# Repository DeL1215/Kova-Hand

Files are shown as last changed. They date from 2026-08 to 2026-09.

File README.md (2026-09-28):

# Kova Hand

[繁體中文](README.md) | [English](README.en.md)

Kova Hand 是一款開源、由腱繩驅動的低成本機械手，核心材料成本控制在新台幣 1,000 元以內。專案包含 3D 列印模型、ESP32-C3 韌體與 Windows 桌面控制軟體，可透過 BLE 獨立控制五根手指，並選用攝影機手勢跟隨或 LLM 自然語言動作控制。

## 成品展示

<p align="center">
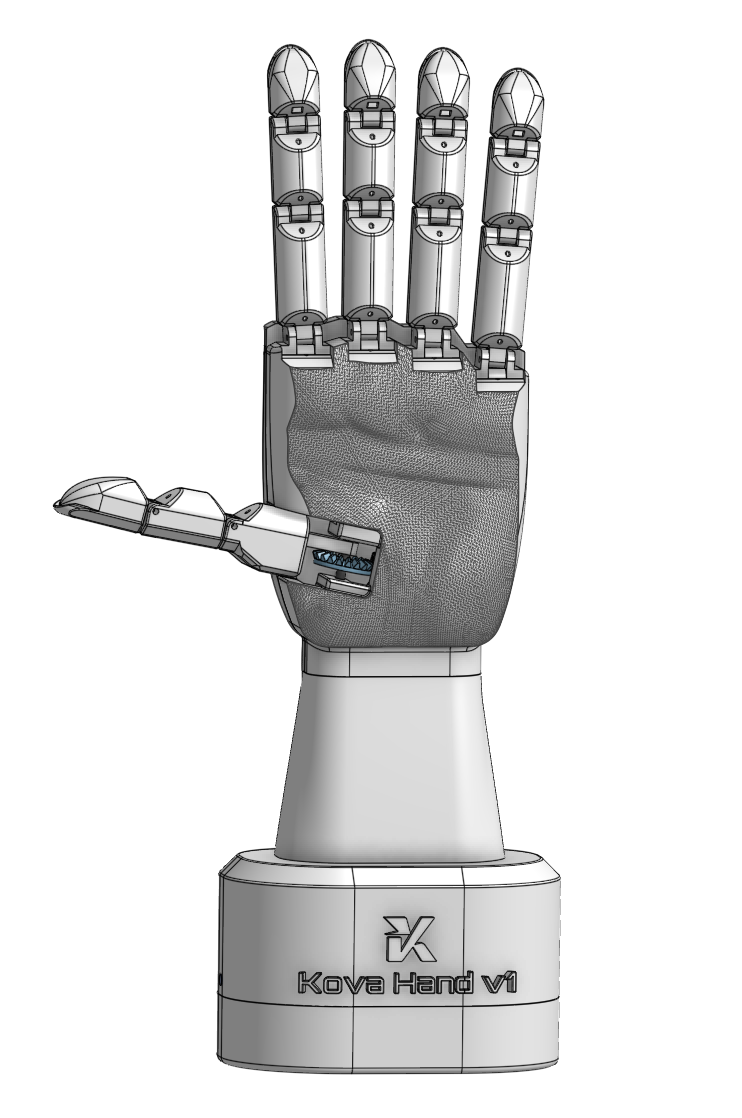
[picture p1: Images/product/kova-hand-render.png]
Kova Hand 機械手模型
  
</p>

### 桌面控制軟體

<p align="center">
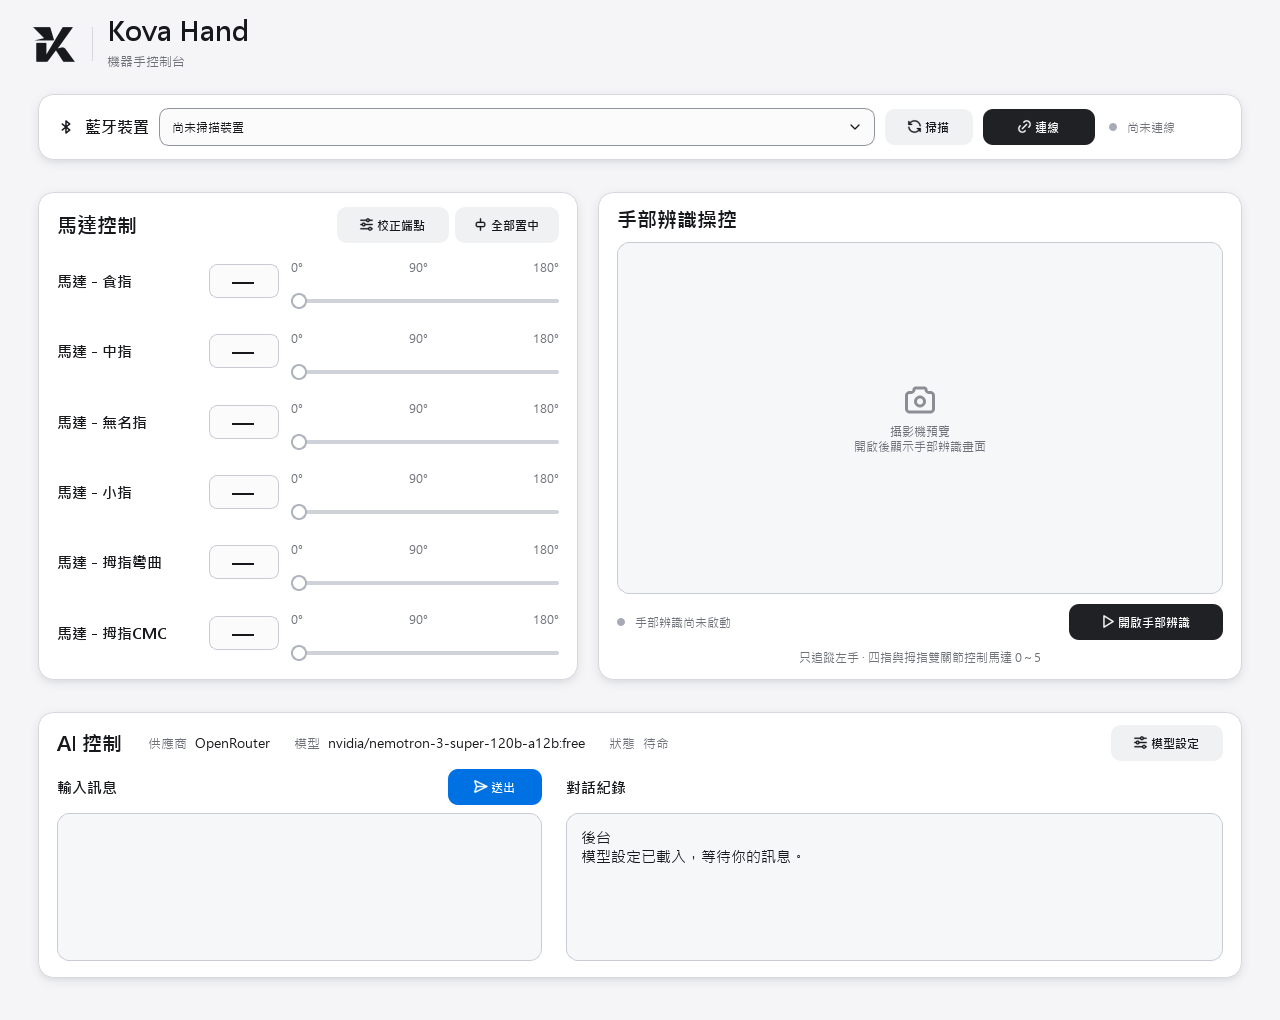
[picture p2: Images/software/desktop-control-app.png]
Kova Hand 桌面控制軟體介面
  
</p>

## 主要功能

- 獨立調整與控制五根手指
- 透過 BLE 無線連接 ESP32-C3 SuperMini
- 使用 MediaPipe 即時辨識並跟隨手部動作
- 透過 LLM 理解自然語言指令並執行對應動作
- 支援伺服馬達端點校正
- 提供圖形化桌面控制軟體

## 硬體需求與材料清單

以下價格為新台幣參考價格，未含運費。

| 材料 | 數量 | 參考價格 | 用途 |
|---|---:|---:|---|
| ESP32-C3 SuperMini 開發板 | 1 | NT$80 | BLE 通訊與主要控制 |
| 已焊接 PCA9685 伺服馬達驅動板 | 1 | NT$98 | 控制六顆伺服馬達 |
| SY8205 5V／5A 降壓模組 | 1 | NT$50 | 將外部電源降壓至 5V，供伺服馬達使用 |
| 5.5 × 2.1 mm DC 母座轉螺絲端子 | 1 | NT$5 | 連接外部電源 |
| MG90S 180° 伺服馬達 | 6 | NT$348 | 控制五根手指，其中拇指使用兩顆 |
| 0.8 mm 以下透明尼龍釣魚線 | 適量 | NT$50 | 作為驅動手指的腱繩 |
| 18～20 AWG 紅黑電源線 | 約 20 cm | NT$5 | 連接 DC 母座、SY8205 與 PCA9685 |
| 2.54 mm 母對母杜邦線 | 4 | NT$10 | 連接 ESP32-C3 SuperMini 與 PCA9685 |
| PLA 或 PETG 3D 列印耗材 | 依據實際用量 | NT$150 | 列印機械手本體與底座 |
| M2 × 6 mm 自攻螺絲 | 20 | NT$20 | 固定機械結構 |
| M2 × 12 mm 自攻螺絲 | 20 | NT$20 | 固定機械結構 |
| Ø2 × 10 mm 定位銷 | 5 | NT$10 | 手指關節定位 |
| Ø2 × 16 mm 定位銷 | 10 | NT$20 | 手指關節定位 |
| Ø3 × 26 mm 定位銷 | 1 | NT$5 | 機械結構定位 |
| 線徑 0.4 × 外徑 4 × 長 70／80 mm 拉伸彈簧 | 5 | NT$20 | 手指回彈 |
| 線徑 0.4 × 外徑 4 × 長 60 mm 拉伸彈簧 | 1 | NT$4 | 拇指回彈 |

**預估核心材料成本：約 NT$895**

3D 列印成本僅估算耗材，不包含印表機、電費與代印費用。

DC 端子須使用 **5.5 mm 外徑、2.1 mm 內徑的母座轉螺絲端子**；SY8205 須選擇 **5V 輸出版本**。

### 材料外觀參考

下圖僅供辨識外觀，請以材料表中的規格與數量為準。

| | | |
|:---:|:---:|:---:|
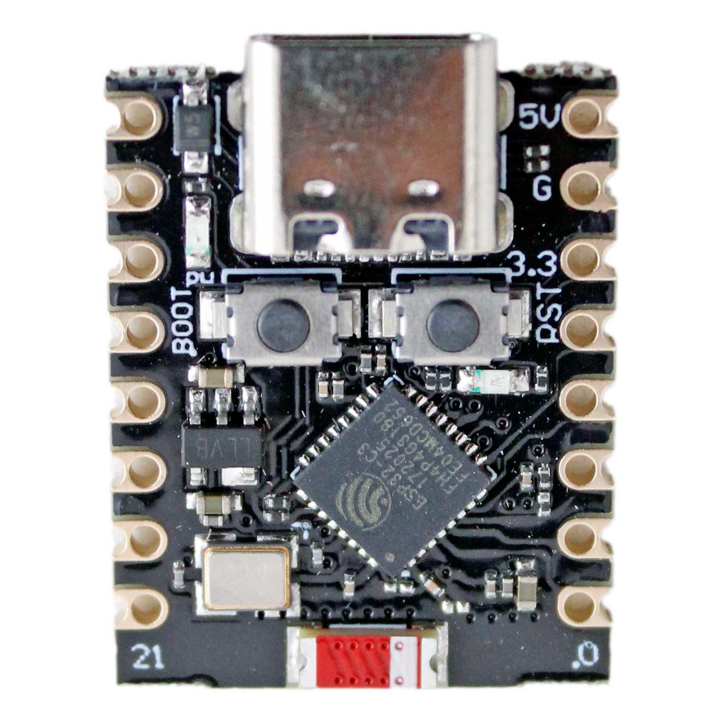
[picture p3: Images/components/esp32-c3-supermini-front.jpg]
ESP32-C3 SuperMini 開發板
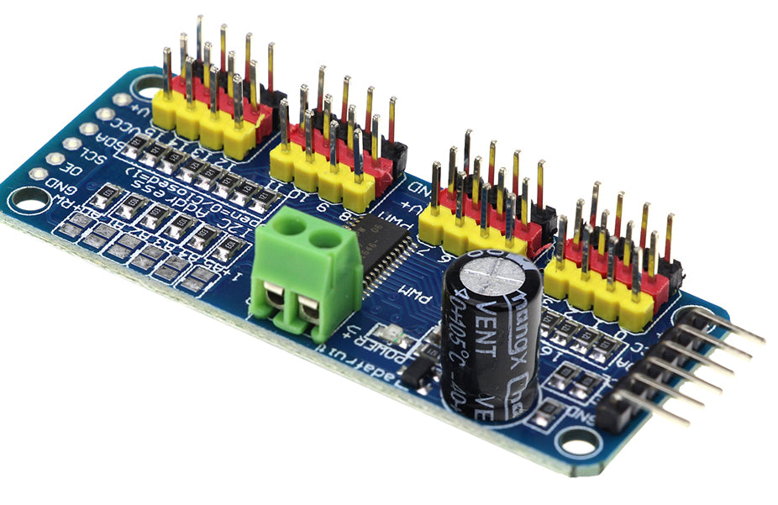
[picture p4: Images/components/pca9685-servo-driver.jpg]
已焊接 PCA9685 伺服馬達驅動板
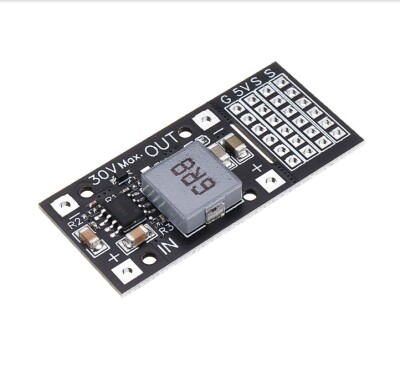
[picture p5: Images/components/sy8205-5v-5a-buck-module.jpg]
SY8205 5V 5A 降壓模組
| <br>ESP32-C3 SuperMini | <br>已焊接 PCA9685 驅動板 | <br>SY8205 5V／5A 降壓模組 |
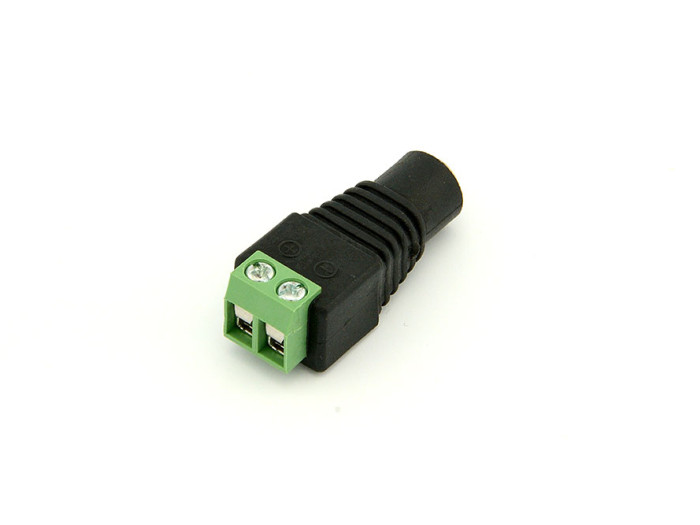
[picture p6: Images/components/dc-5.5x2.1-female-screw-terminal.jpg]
5.5 × 2.1 mm DC 母座轉螺絲端子
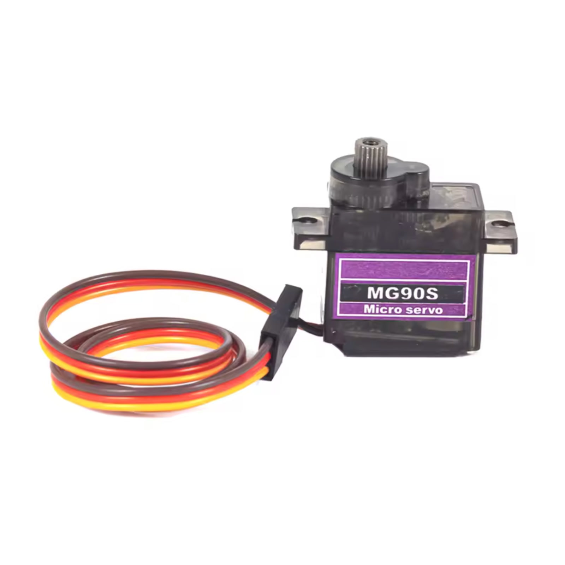
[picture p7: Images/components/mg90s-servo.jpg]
MG90S 180 度伺服馬達
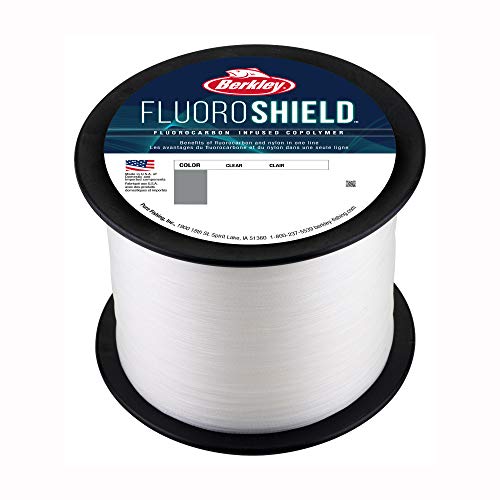
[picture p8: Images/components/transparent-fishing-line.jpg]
透明尼龍釣魚線
| <br>5.5 × 2.1 mm DC 母座 | <br>MG90S 伺服馬達 | <br>透明尼龍釣魚線 |
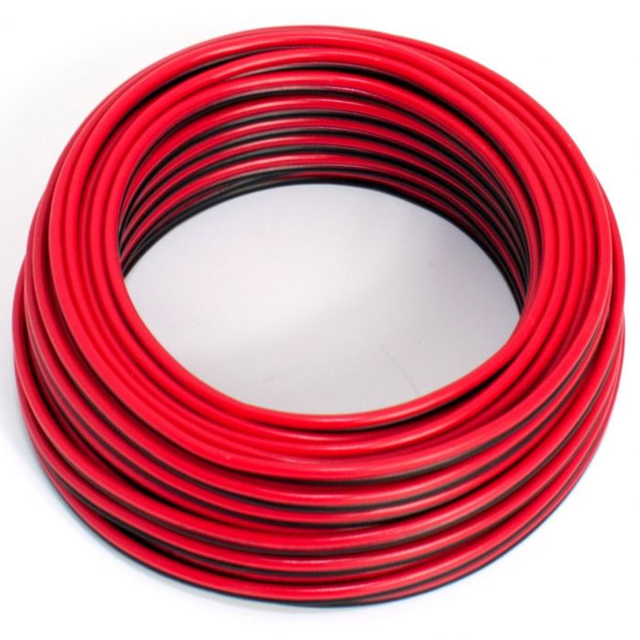
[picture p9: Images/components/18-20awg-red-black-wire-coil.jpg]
18 至 20 AWG 紅黑電源線線捲
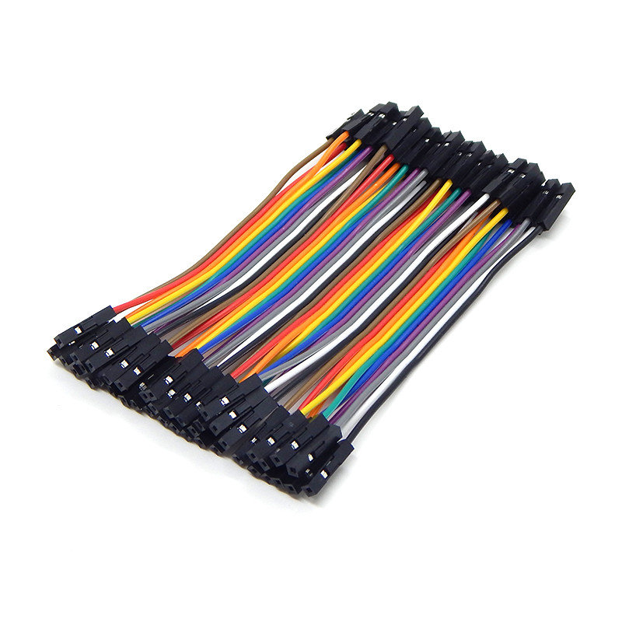
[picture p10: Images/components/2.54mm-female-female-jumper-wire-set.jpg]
多色 2.54 mm 母對母杜邦線組
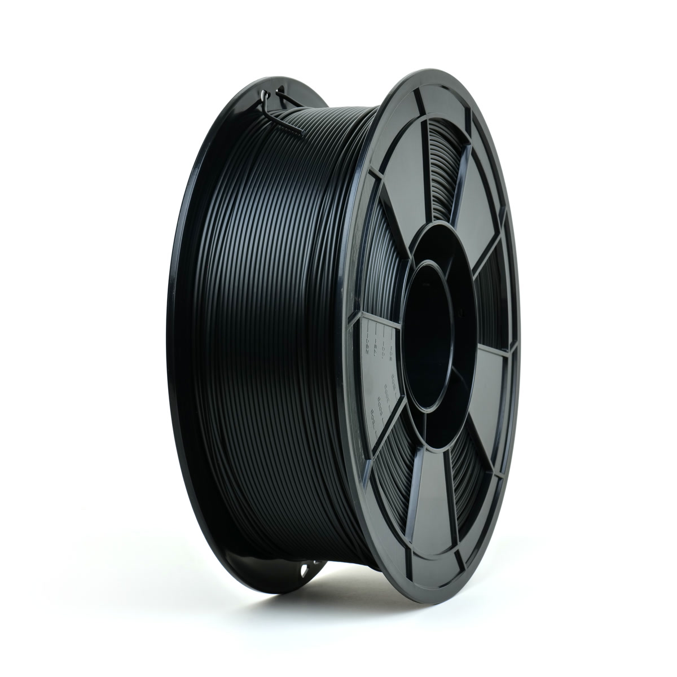
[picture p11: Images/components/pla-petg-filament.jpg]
PLA 或 PETG 列印耗材
| <br>18～20 AWG 紅黑電源線 | <br>2.54 mm 母對母杜邦線 | <br>PLA／PETG 列印耗材 |
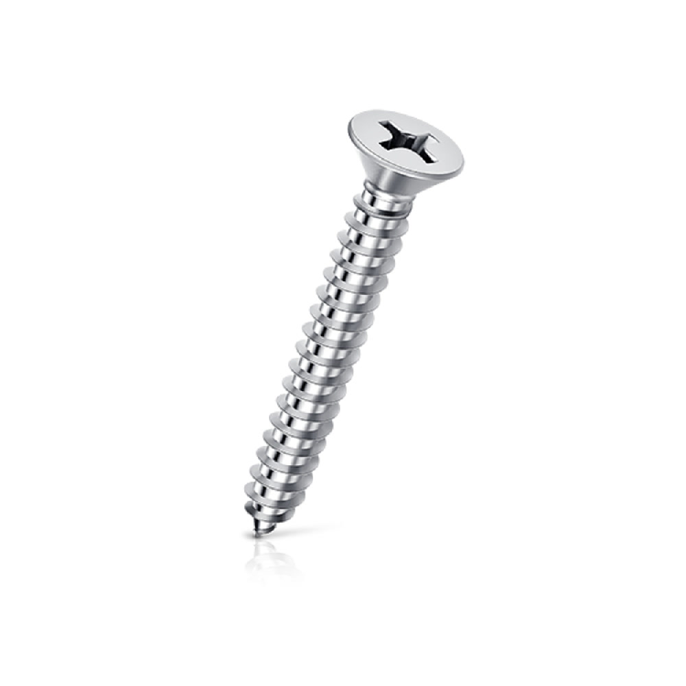
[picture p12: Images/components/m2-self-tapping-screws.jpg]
M2 自攻螺絲
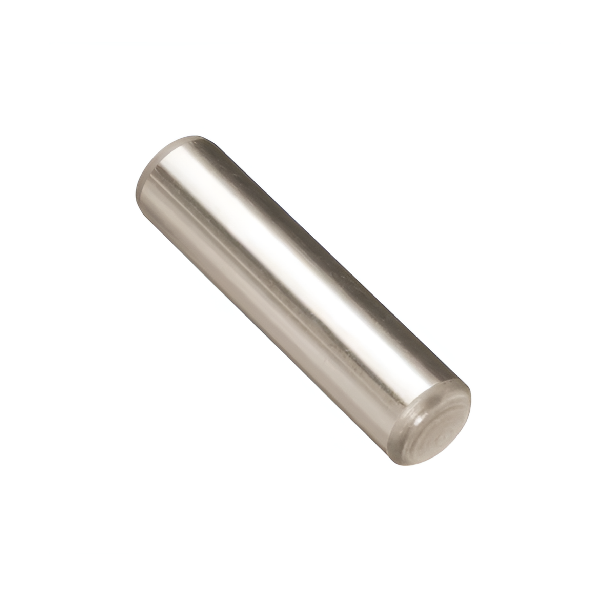
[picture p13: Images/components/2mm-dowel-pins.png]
2 mm 定位銷
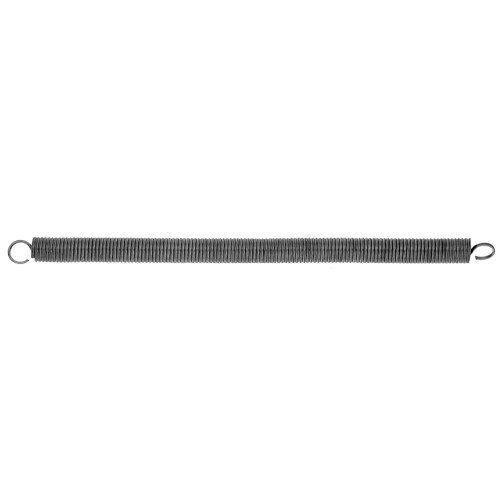
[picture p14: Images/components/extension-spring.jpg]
拉伸彈簧
| <br>M2 自攻螺絲 | <br>2 mm 定位銷 | <br>拉伸彈簧 |

### 額外設備

- USB Type-C 傳輸線，用於 ESP32-C3 SuperMini 燒錄與除錯
- DC 電源線與電源供應器
- 攝影機，僅手部動作跟隨功能需要

## 3D 列印模型

<p align="center">
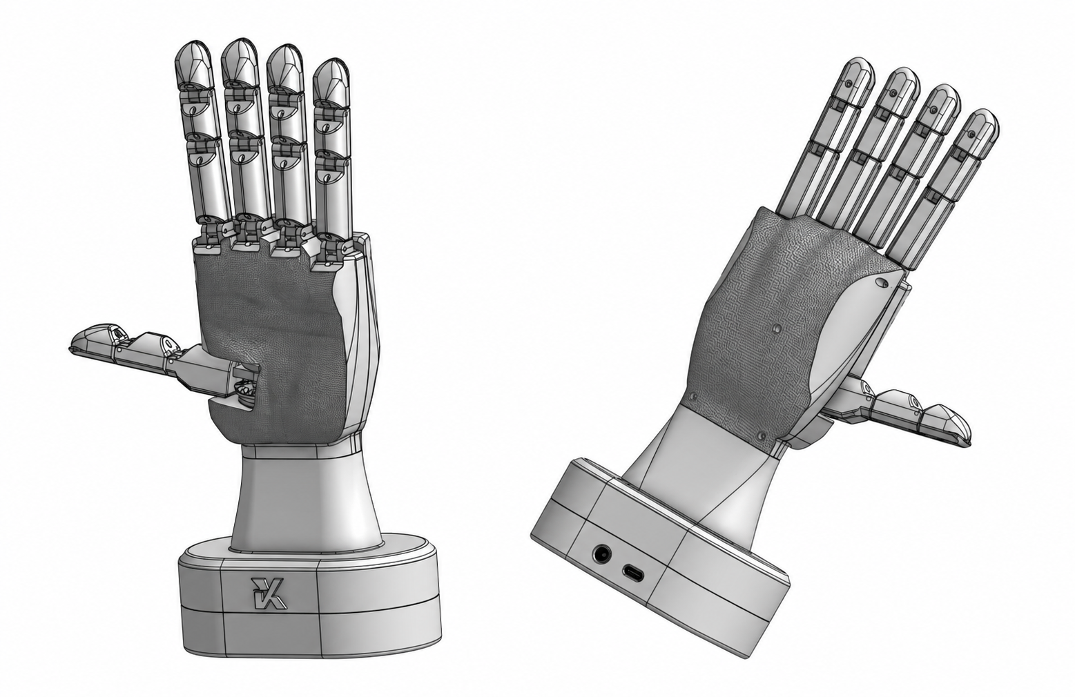
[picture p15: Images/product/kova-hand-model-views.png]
Kova Hand 3D 模型雙視角
  
</p>

可在 [Onshape 線上模型](https://cad.onshape.com/documents/ccffffec5822f67dead6a1cb/w/ebebf107b7355267c1a8c3b4/e/881fbe2581adab1d2883eabd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) 檢視模型與組裝結構。

### STL 模型

STL 模型將透過 [GitHub Releases](https://github.com/DeL1215/Kova-Hand/releases) 提供。

### Bambu Studio 3MF 配置

另提供 Bambu Studio 3MF 列印配置。

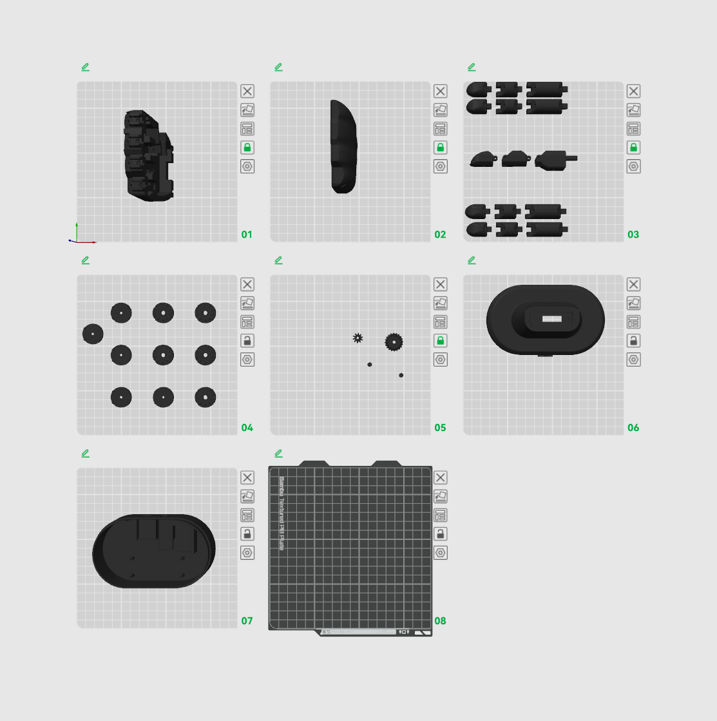
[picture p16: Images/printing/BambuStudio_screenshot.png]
Kova Hand 零件在 Bambu Studio 中的列印配置


> [!WARNING]
> **齒輪不建議使用啞光 PLA 或其他啞光耗材。** 啞光材料通常較脆，齒牙受力時容易崩斷；建議改用一般 PLA、PLA+ 或韌性較好的 PETG。

## 電路接線

Kova Hand 電路接線圖

| 來源 | 連接至 |
|---|---|
| DC 母座 `+` | SY8205 `IN+` |
| DC 母座 `−` | SY8205 `IN−` |
| SY8205 `OUT+` | PCA9685 `V+` |
| SY8205 `OUT−` | PCA9685 電源端子 `GND` |
| ESP32-C3 `3.3V` | PCA9685 `VCC` |
| ESP32-C3 `GPIO8` | PCA9685 `SDA` |
| ESP32-C3 `GPIO9` | PCA9685 `SCL` |
| ESP32-C3 `GND` | PCA9685 `GND` |

PCA9685 的 CH0～CH5 依序連接食指、中指、無名指、小指、拇指彎曲與拇指 CMC 伺服馬達。

## 韌體燒錄

韌體支援 PlatformIO 與 Arduino IDE。

### PlatformIO

1. 安裝 Visual Studio Code 與 PlatformIO IDE 擴充套件。
2. 使用 PlatformIO 開啟專案中的 `firmware` 資料夾。
3. 使用具備資料傳輸功能的 USB Type-C 線連接 ESP32-C3 SuperMini。
4. 選擇環境 `esp32-c3-devkitm-1`，點擊 **Upload**。

### Arduino IDE

1. 安裝 **ESP32 by Espressif Systems 2.0.17**。
2. 在函式庫管理員安裝：
   - `Adafruit PWM Servo Driver Library 3.0.3`
   - `NimBLE-Arduino 1.4.3`
3. 開啟 `firmware/KovaHand/KovaHand.ino`。
4. 選擇 **ESP32C3 Dev Module** 與正確的連接埠，將 **USB CDC On Boot** 設為 **Enabled**。
5. 點擊 **上傳**。

## 軟體安裝

### 系統需求

- Windows 10 或 11，並具備 Bluetooth Low Energy
- Python 3.11
- Git
- 網路連線，用於安裝套件與下載 MediaPipe 模型

攝影機與 LLM API Key 為選用項目。

### 1. 下載專案

```powershell
git clone https://github.com/DeL1215/Kova-Hand.git
cd Kova-Hand
```

### 2. 建立虛擬環境

```powershell
py -3.11 -m venv kova-hand-env
.\kova-hand-env\Scripts\Activate.ps1
```

### 3. 安裝必要套件

```powershell
python -m pip install -r requirements.txt
```

### 4. 下載手部辨識模型

```powershell
python scripts\download_hand_model.py
```

### 5. 確認安裝結果

```powershell
python scripts\check_install.py
```

## 啟動控制軟體

在專案根目錄執行：

```powershell
.\kova-hand-env\Scripts\Activate.ps1
python desktop-app\main.py
```

## 專案結構

```text
Kova-Hand/
├── Images/
│   ├── components/              # 電子零件參考圖
│   ├── printing/                # 列印配置畫面
│   ├── product/                 # 成品與模型展示圖
│   ├── software/                # 軟體介面畫面
│   └── wiring/                  # 電路接線圖
├── desktop-app/                 # 桌面控制軟體
│   ├── main.py                  # BLE 與手部辨識
│   ├── qt_ui.py                 # 圖形介面
│   ├── ai_chat.py               # LLM 控制
│   ├── config.py                # 控制參數
│   └── tests/                   # 軟體測試
├── firmware/
│   ├── KovaHand/KovaHand.ino    # Arduino IDE 韌體
│   ├── src/main.cpp             # PlatformIO 入口
│   └── platformio.ini           # PlatformIO 設定
├── scripts/
│   ├── download_hand_model.py   # 下載手部辨識模型
│   └── check_install.py         # 檢查安裝環境
├── .env.example                 # LLM 設定範例
├── requirements.txt             # Python 依賴
├── LICENSE-CODE                 # 程式碼授權
├── LICENSE-HARDWARE             # 模型與硬體授權
├── NOTICE                       # 第三方授權與告知事項
├── TRADEMARKS.md                # 名稱與 Logo 使用規範
├── README.md                    # 繁體中文說明
└── README.en.md                 # English documentation（規劃中）
```

## 開發狀態

核心硬體與控制功能已完成，目前以 Demo 版本發布。

## 授權

- 程式碼採用 [MIT License](LICENSE-CODE)。
- 3D 模型、硬體設計與專案文件採用 [CC BY-NC-SA 4.0](LICENSE-HARDWARE)。
- Kova Hand 名稱與 Logo 不包含在上述授權中，詳見 [TRADEMARKS.md](TRADEMARKS.md)。
- 商業使用 3D 模型或硬體設計前，請透過 GitHub 專案擁有者公開的聯絡方式洽談商業授權。

Copyright © 2026 Kova Hand Project

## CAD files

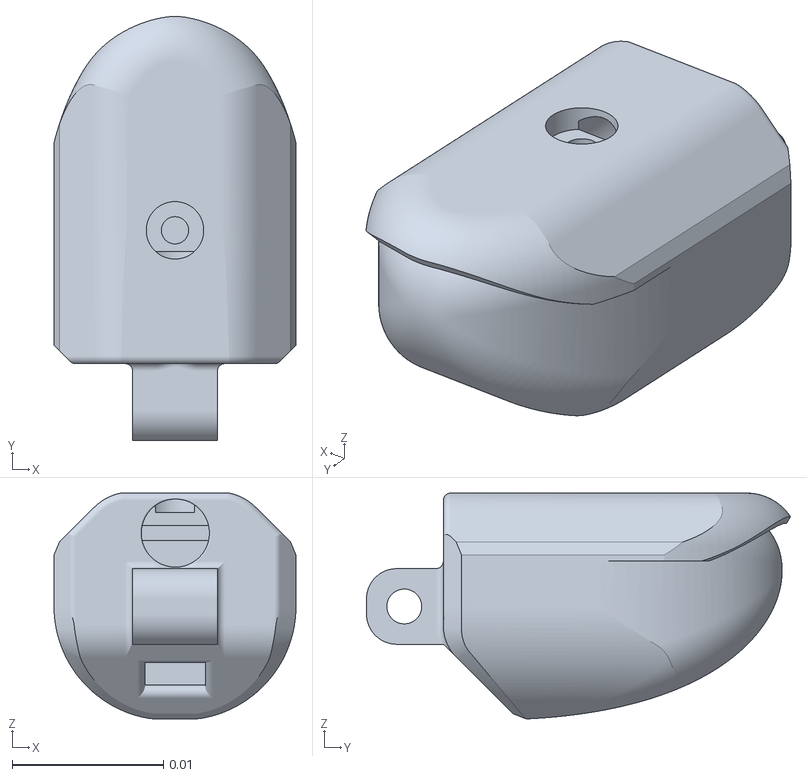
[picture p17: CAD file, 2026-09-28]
Models/DIP.stl
0.016 x 0.028 x 0.0149

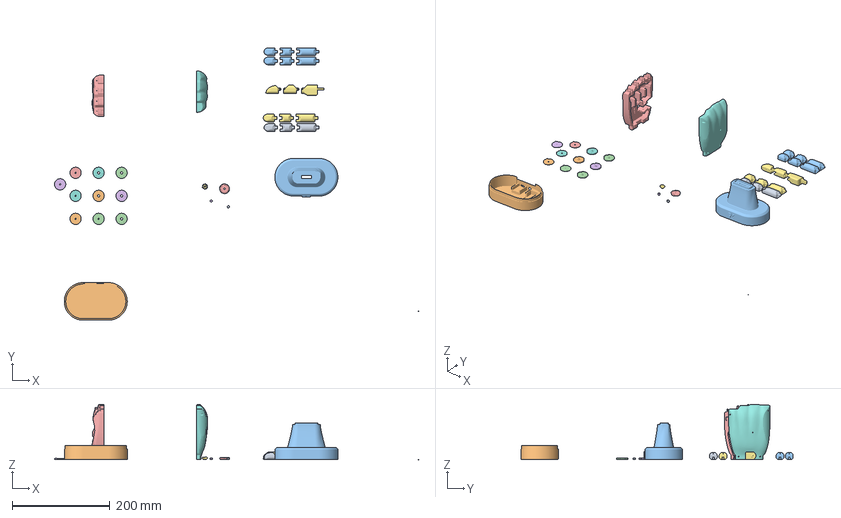
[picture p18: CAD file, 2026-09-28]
Printing.3mf
745.0 x 557.5 x 113.0 mm
收線舵盤.stl
Base1.stl
Base2.stl
Servo_Tendon_Spool_Part1.stl x 5
Gear_big
Gear_small
Part Studio 1 - Part 9.stl x 2
Finger x 4
Servo_Tendon_Spool_Part2.stl x 5
Hand_Front.stl
Thumb
Hand_Back.stl

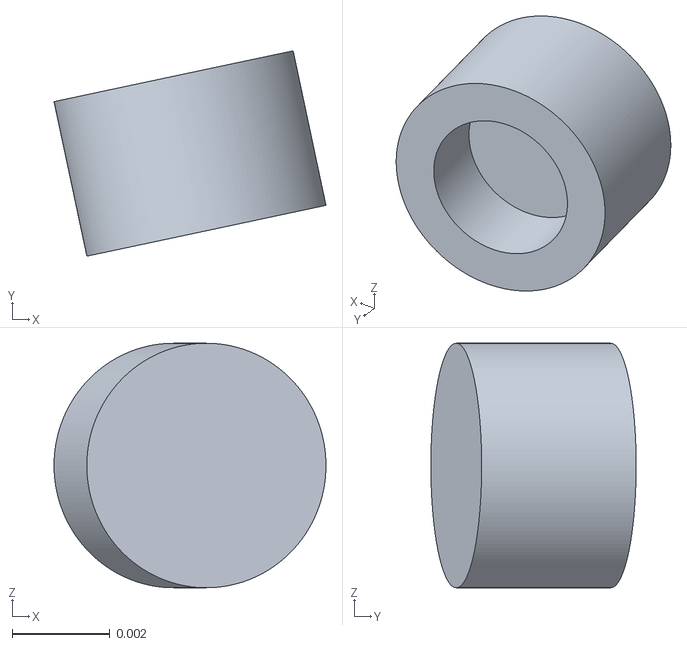
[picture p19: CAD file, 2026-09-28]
Models/Part 9.stl
0.00556 x 0.0042 x 0.005

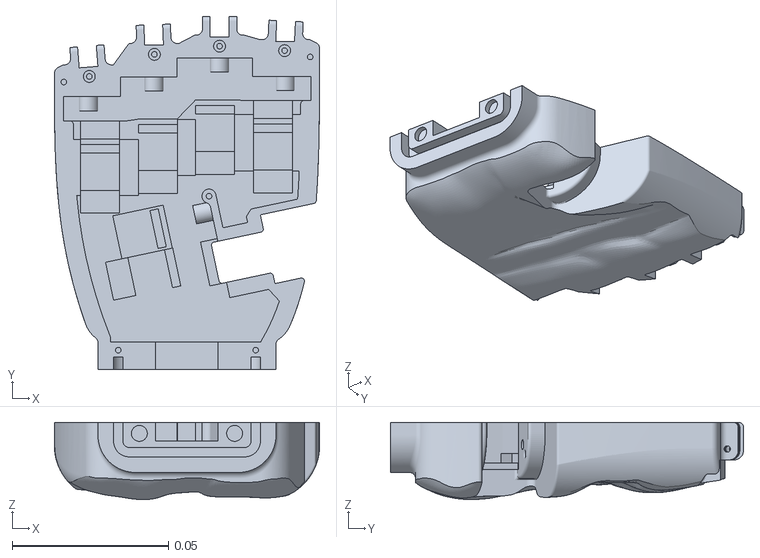
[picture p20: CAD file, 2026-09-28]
Models/Hand_Front.stl
0.0849 x 0.113 x 0.0247

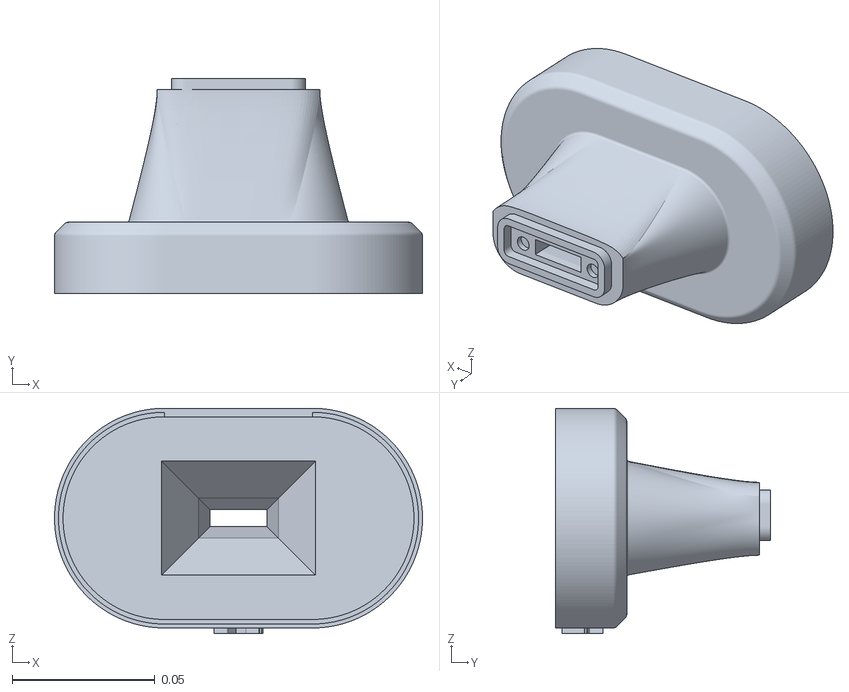
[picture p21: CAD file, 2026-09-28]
Models/Base2.stl
0.129 x 0.0754 x 0.079

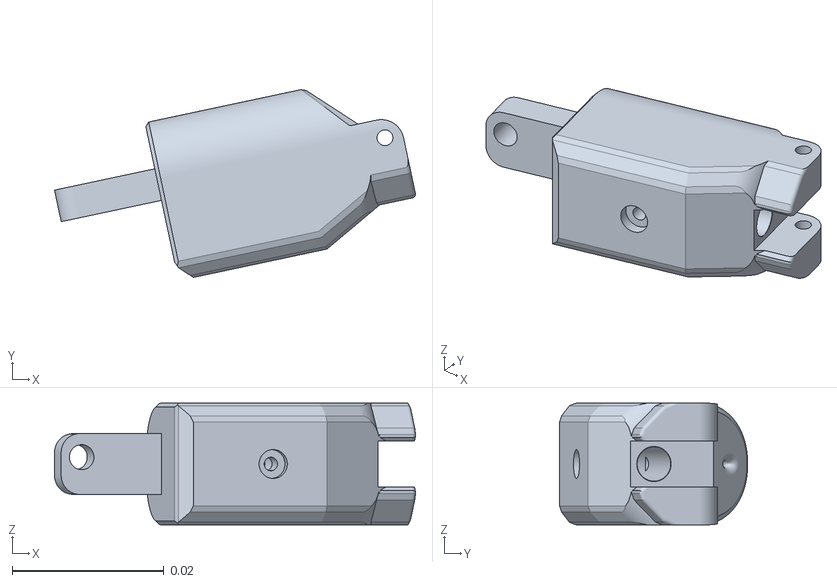
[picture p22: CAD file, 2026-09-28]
Models/thumb_CMC.stl
0.0475 x 0.0247 x 0.016

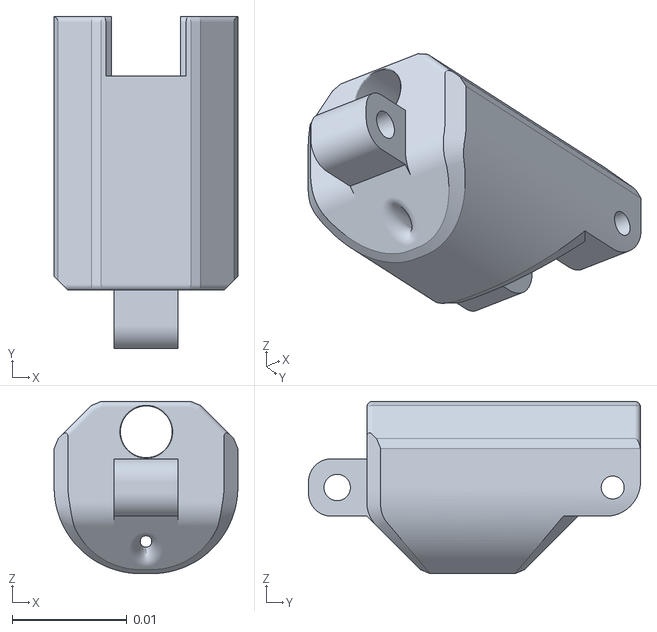
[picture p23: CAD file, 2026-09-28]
Models/PIP.stl
0.016 x 0.0289 x 0.015

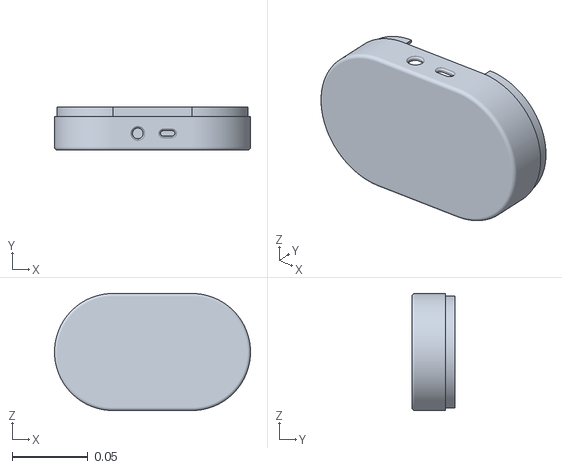
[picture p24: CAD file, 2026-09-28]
Models/Base1.stl
0.129 x 0.0285 x 0.077

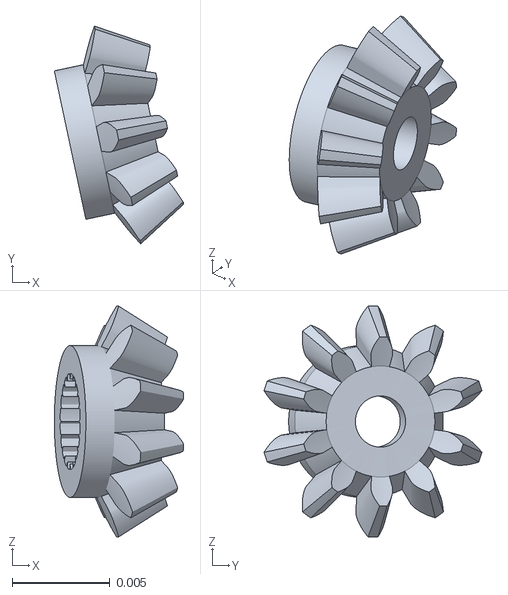
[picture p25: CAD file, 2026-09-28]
Models/Gear_small.stl
0.00662 x 0.0111 x 0.0118

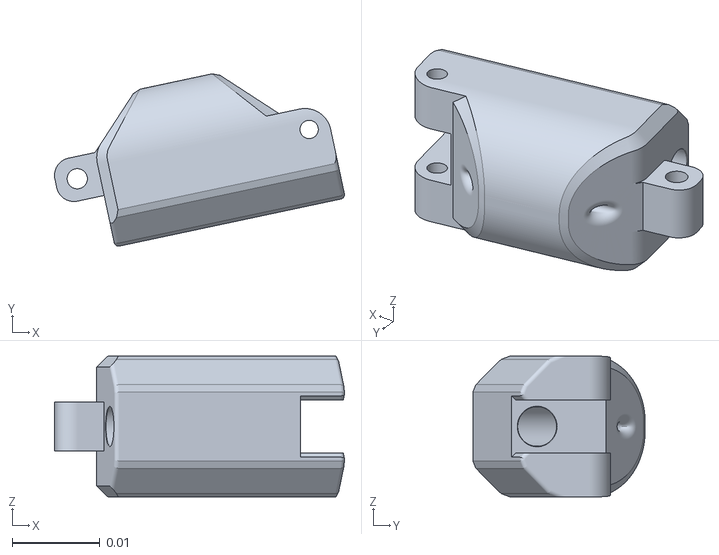
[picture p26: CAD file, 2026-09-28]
Models/thumb_PIP.stl
0.033 x 0.0196 x 0.016

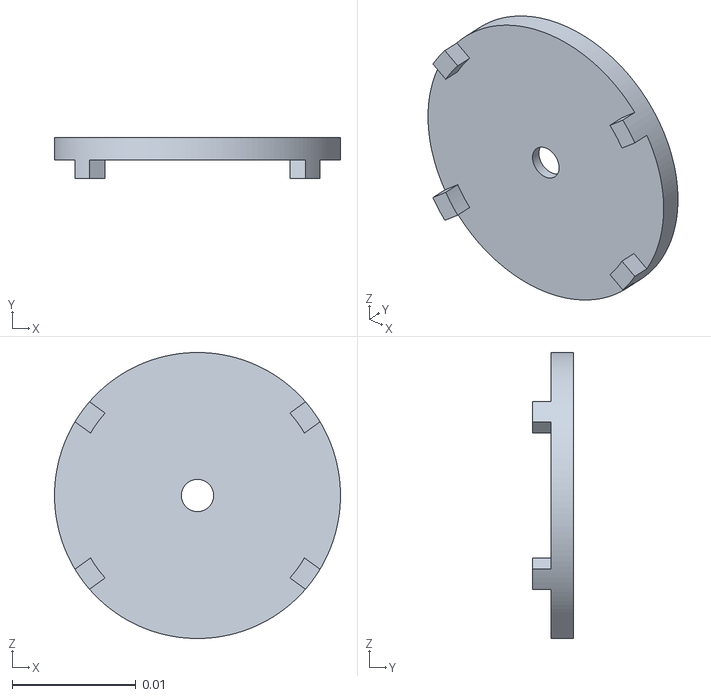
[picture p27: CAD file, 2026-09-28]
Models/Servo_Tendon_Spool_Part1.stl
0.0231 x 0.0033 x 0.0231

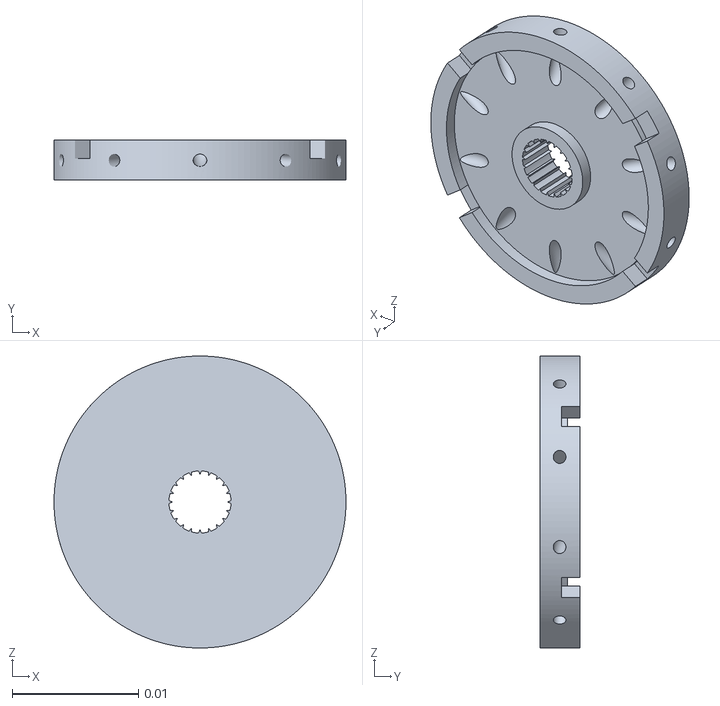
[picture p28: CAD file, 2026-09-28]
Models/Servo_Tendon_Spool_Part2.stl
0.0231 x 0.0032 x 0.0231

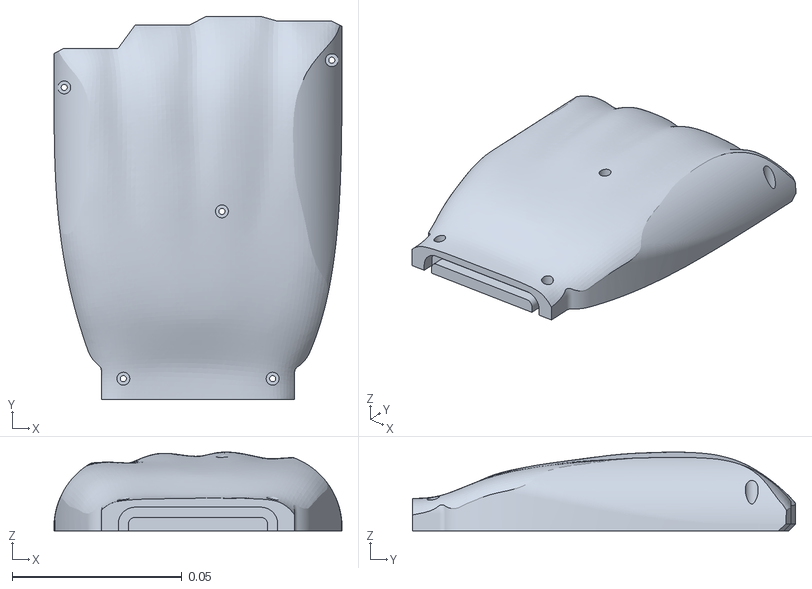
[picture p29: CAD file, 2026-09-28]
Models/Hand_Back.stl
0.0849 x 0.113 x 0.0232

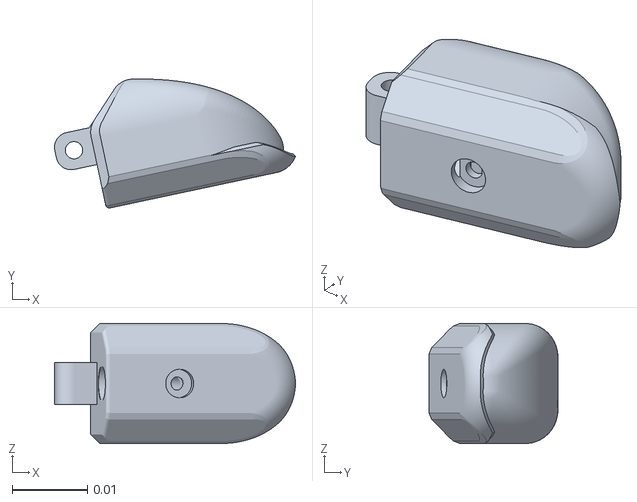
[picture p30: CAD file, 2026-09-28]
Models/thumb_DIP.stl
0.032 x 0.0171 x 0.016

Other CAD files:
列印.3mf
Models/MCP.stl
Models/Gear_big.stl

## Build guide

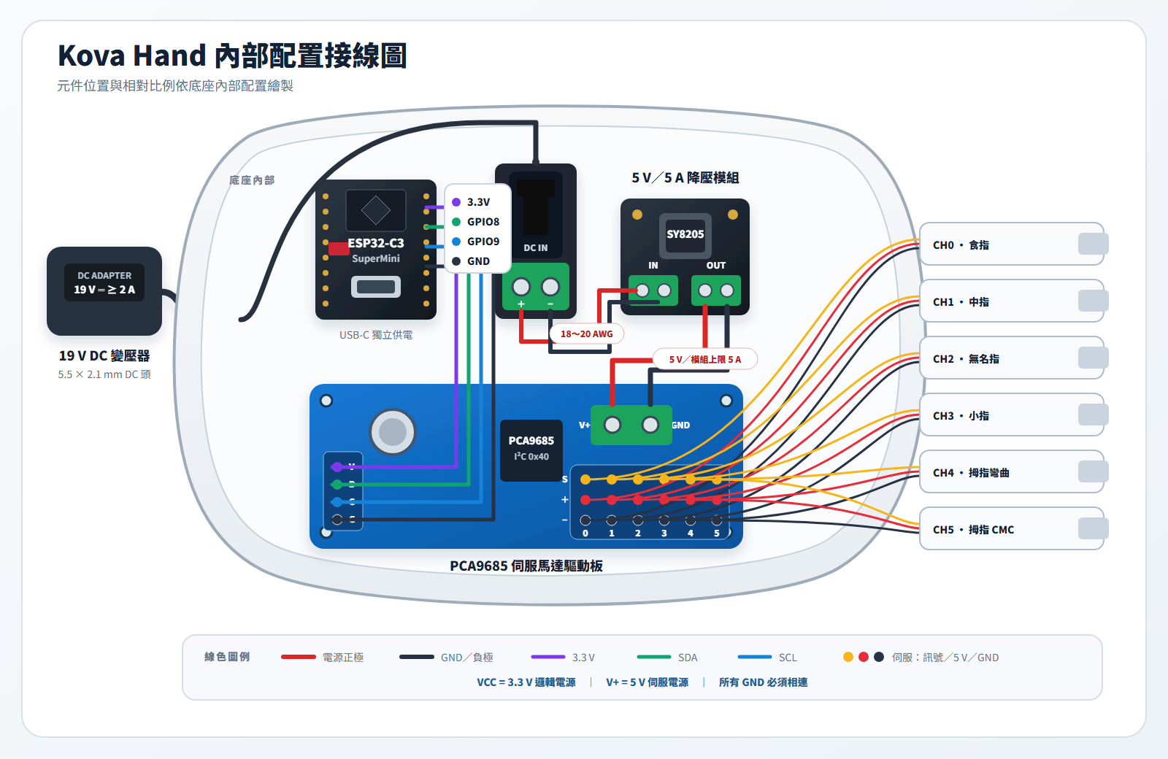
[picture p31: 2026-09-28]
Images/wiring/kova-hand-wiring.png

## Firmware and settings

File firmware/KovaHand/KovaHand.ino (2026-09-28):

// SPDX-FileCopyrightText: 2026 Kova Hand Project
// SPDX-License-Identifier: MIT

#include <Arduino.h>
#include <Wire.h>
#include <Adafruit_PWMServoDriver.h>
#include <NimBLEDevice.h>
#include <Preferences.h>

// ============================================================
// Kova Hand：ESP32-C3 + PCA9685 + BLE 六路舵機控制器
// 單路指令：S,通道,角度\n，例如 S,0,90
// 六馬達同步指令：7 bytes，'B' 後接 channel 0～5 的 uint8 角度。
// ============================================================

namespace Config {

// ESP32-C3 連接 PCA9685 的 I2C 腳位。
constexpr uint8_t SDA_PIN = 8;
constexpr uint8_t SCL_PIN = 9;

constexpr uint8_t PCA9685_ADDRESS = 0x40;
constexpr uint8_t SERVO_COUNT = 6;
constexpr uint16_t SERVO_FREQUENCY_HZ = 50;
constexpr uint16_t SERVO_UPDATE_INTERVAL_MS = 20;
// 20 ms 走 8 度：仍有漸進移動，但不會明顯落後於手勢。
constexpr uint8_t SERVO_MAX_STEP_DEG = 8;
constexpr uint8_t SERVO_START_ANGLE_DEG = 0;

// 每顆舵機獨立校正。舊馬達沿用原本可到 180° 的端點；
// 新批次 MG90S 使用較短脈寬，避免在終點撞限位後回抽。
struct ServoPulseRange {
  uint16_t minimum;
  uint16_t maximum;
};

constexpr ServoPulseRange DEFAULT_SERVO_PULSE_RANGES[SERVO_COUNT] = {
    {150, 600},  // 0: 食指，舊馬達
    {150, 480},  // 1: 中指，新馬達
    {150, 600},  // 2: 無名指，舊馬達
    {150, 600},  // 3: 小指，舊馬達
    {150, 480},  // 4: 拇指彎曲，新馬達
    {150, 600},  // 5: 拇指 CMC，舊馬達
};

constexpr uint16_t SERVO_PULSE_FLOOR = 80;
constexpr uint16_t SERVO_PULSE_CEILING = 650;
constexpr uint16_t SERVO_PULSE_MIN_SPAN = 40;

// 必須與 desktop-app/config.py 完全一致。
constexpr char BLE_DEVICE_NAME[] = "Kova-Hand";
constexpr char BLE_SERVICE_UUID[] = "19b10000-e8f2-537e-4f6c-d104768a1214";
constexpr char BLE_CHARACTERISTIC_UUID[] = "19b10001-e8f2-537e-4f6c-d104768a1214";

}  // namespace Config

Adafruit_PWMServoDriver pwm(Config::PCA9685_ADDRESS);
Config::ServoPulseRange servoPulseRanges[Config::SERVO_COUNT];
int currentAngles[Config::SERVO_COUNT] = {};
int targetAngles[Config::SERVO_COUNT] = {};
bool servoEnabled[Config::SERVO_COUNT] = {};

bool validPulseRange(uint16_t minimum, uint16_t maximum) {
  return minimum >= Config::SERVO_PULSE_FLOOR &&
         maximum <= Config::SERVO_PULSE_CEILING &&
         maximum >= minimum + Config::SERVO_PULSE_MIN_SPAN;
}

void loadServoCalibration() {
  Preferences storage;
  const bool opened = storage.begin("servo-pwm", true);
  for (uint8_t channel = 0; channel < Config::SERVO_COUNT; ++channel) {
    const auto defaults = Config::DEFAULT_SERVO_PULSE_RANGES[channel];
    if (!opened) {
      servoPulseRanges[channel] = defaults;
      continue;
    }
    char minKey[8];
    char maxKey[8];
    snprintf(minKey, sizeof(minKey), "m%umin", channel);
    snprintf(maxKey, sizeof(maxKey), "m%umax", channel);
    const uint16_t minimum = storage.getUShort(minKey, defaults.minimum);
    const uint16_t maximum = storage.getUShort(maxKey, defaults.maximum);
    servoPulseRanges[channel] = validPulseRange(minimum, maximum)
        ? Config::ServoPulseRange{minimum, maximum}
        : defaults;
  }
  if (opened) {
    storage.end();
  }
}

bool saveServoCalibration(uint8_t channel, uint16_t minimum, uint16_t maximum) {
  if (channel >= Config::SERVO_COUNT || !validPulseRange(minimum, maximum)) {
    return false;
  }
  Preferences storage;
  if (!storage.begin("servo-pwm", false)) {
    return false;
  }
  char minKey[8];
  char maxKey[8];
  snprintf(minKey, sizeof(minKey), "m%umin", channel);
  snprintf(maxKey, sizeof(maxKey), "m%umax", channel);
  const bool saved = storage.putUShort(minKey, minimum) == sizeof(uint16_t) &&
                     storage.putUShort(maxKey, maximum) == sizeof(uint16_t);
  storage.end();
  if (saved) {
    servoPulseRanges[channel] = {minimum, maximum};
  }
  return saved;
}

void restoreServoState() {
  for (uint8_t channel = 0; channel < Config::SERVO_COUNT; ++channel) {
    const Config::ServoPulseRange& range = servoPulseRanges[channel];
    const uint16_t pulse = pwm.getPWM(channel, true);
    if (pulse < range.minimum || pulse > range.maximum) {
      continue;
    }

    const int pulseSpan = range.maximum - range.minimum;
    const int angle = ((pulse - range.minimum) * 180 + pulseSpan / 2) / pulseSpan;
    currentAngles[channel] = angle;
    targetAngles[channel] = angle;
    servoEnabled[channel] = true;
  }
}

void writeServoAngle(uint8_t channel, int angle) {
  if (channel >= Config::SERVO_COUNT) {
    return;
  }

  angle = constrain(angle, 0, 180);
  const Config::ServoPulseRange& range = servoPulseRanges[channel];
  const uint16_t pulse = map(
      angle,
      0,
      180,
      range.minimum,
      range.maximum);

  pwm.setPWM(channel, 0, pulse);
}

void setServoTarget(uint8_t channel, int angle) {
  if (channel >= Config::SERVO_COUNT) {
    return;
  }

  angle = constrain(angle, 0, 180);
  targetAngles[channel] = angle;

  // 第一次命令從預設零度漸進移動，避免多馬達同時瞬間跳角度的電流尖峰。
  if (!servoEnabled[channel]) {
    servoEnabled[channel] = true;
    currentAngles[channel] = Config::SERVO_START_ANGLE_DEG;
    if (currentAngles[channel] == targetAngles[channel]) {
      writeServoAngle(channel, currentAngles[channel]);
    }
  }
}

void updateServos() {
  static uint32_t lastUpdateMs = 0;
  const uint32_t now = millis();
  if (now - lastUpdateMs < Config::SERVO_UPDATE_INTERVAL_MS) {
    return;
  }
  lastUpdateMs = now;

  for (uint8_t channel = 0; channel < Config::SERVO_COUNT; ++channel) {
    if (!servoEnabled[channel] || currentAngles[channel] == targetAngles[channel]) {
      continue;
    }

    const int difference = targetAngles[channel] - currentAngles[channel];
    const int step = constrain(
        difference,
        -static_cast<int>(Config::SERVO_MAX_STEP_DEG),
        static_cast<int>(Config::SERVO_MAX_STEP_DEG));
    currentAngles[channel] += step;
    writeServoAngle(channel, currentAngles[channel]);
  }
}

class ServoCommandCallbacks final : public NimBLECharacteristicCallbacks {
  void onRead(NimBLECharacteristic* characteristic) override {
    uint8_t state[Config::SERVO_COUNT];
    for (uint8_t channel = 0; channel < Config::SERVO_COUNT; ++channel) {
      state[channel] = servoEnabled[channel] ? currentAngles[channel] : 0xFF;
    }
    characteristic->setValue(state, sizeof(state));
  }

  void onWrite(NimBLECharacteristic* characteristic) override {
    const std::string command = characteristic->getValue();

    int calibrationChannel = -1;
    unsigned int minimumPulse = 0;
    unsigned int maximumPulse = 0;
    if (sscanf(
            command.c_str(),
            "C,%d,%u,%u",
            &calibrationChannel,
            &minimumPulse,
            &maximumPulse) == 3) {
      const bool valid = calibrationChannel >= 0 &&
                         calibrationChannel < Config::SERVO_COUNT &&
                         minimumPulse <= UINT16_MAX && maximumPulse <= UINT16_MAX;
      if (!valid || !saveServoCalibration(
                        static_cast<uint8_t>(calibrationChannel),
                        static_cast<uint16_t>(minimumPulse),
                        static_cast<uint16_t>(maximumPulse))) {
        Serial.println("Invalid servo calibration");
        return;
      }
      Serial.printf(
          "Servo %d calibration -> %u..%u ticks\n",
          calibrationChannel,
          minimumPulse,
          maximumPulse);
      return;
    }

    if (command.size() == Config::SERVO_COUNT + 1 && command[0] == 'B') {
      for (uint8_t channel = 0; channel < Config::SERVO_COUNT; ++channel) {
        if (static_cast<uint8_t>(command[channel + 1]) > 180) {
          Serial.println("Binary hand command out of range");
          return;
        }
      }
      for (uint8_t channel = 0; channel < Config::SERVO_COUNT; ++channel) {
        const uint8_t angle = static_cast<uint8_t>(command[channel + 1]);
        setServoTarget(channel, angle);
      }
      return;
    }

    int channel = -1;
    int angle = -1;

    if (sscanf(command.c_str(), "S,%d,%d", &channel, &angle) != 2) {
      Serial.printf("Invalid command: %s\n", command.c_str());
      return;
    }

    if (channel < 0 || channel >= Config::SERVO_COUNT ||
        angle < 0 || angle > 180) {
      Serial.printf("Out of range: channel=%d angle=%d\n", channel, angle);
      return;
    }

    setServoTarget(static_cast<uint8_t>(channel), angle);
    Serial.printf("Servo %d target -> %d degrees\n", channel, angle);
  }
};

class ServerCallbacks final : public NimBLEServerCallbacks {
  void onConnect(NimBLEServer* server) override {
    Serial.println("BLE client connected");
  }

  void onDisconnect(NimBLEServer* server) override {
    Serial.println("BLE client disconnected; advertising restarted");
    NimBLEDevice::startAdvertising();
  }
};

void setupBle() {
  NimBLEDevice::init(Config::BLE_DEVICE_NAME);

  NimBLEServer* server = NimBLEDevice::createServer();
  server->setCallbacks(new ServerCallbacks());

  NimBLEService* service = server->createService(Config::BLE_SERVICE_UUID);
  NimBLECharacteristic* commandCharacteristic = service->createCharacteristic(
      Config::BLE_CHARACTERISTIC_UUID,
      NIMBLE_PROPERTY::READ | NIMBLE_PROPERTY::WRITE | NIMBLE_PROPERTY::WRITE_NR);

  commandCharacteristic->setCallbacks(new ServoCommandCallbacks());
  service->start();

  NimBLEAdvertising* advertising = NimBLEDevice::getAdvertising();

  // BLE 4.x 每個廣播封包最多 31 bytes。完整名稱與 128-bit UUID
  // 若由函式庫自動塞入同一封包，Windows 有時只會收到「未命名裝置」。
  // 因此主廣播固定放名稱，scan response 固定放 Service UUID。
  NimBLEAdvertisementData advertisementData;
  advertisementData.setFlags(0x06);  // General discoverable + BR/EDR not supported
  advertisementData.setName(Config::BLE_DEVICE_NAME);

  NimBLEAdvertisementData scanResponseData;
  scanResponseData.setCompleteServices(NimBLEUUID(Config::BLE_SERVICE_UUID));

  advertising->setAdvertisementData(advertisementData);
  advertising->setScanResponseData(scanResponseData);
  const bool advertisingStarted = advertising->start();

  Serial.printf("BLE address: %s\n", NimBLEDevice::getAddress().toString().c_str());
  Serial.printf("BLE advertising started: %s\n", advertisingStarted ? "yes" : "NO");
}

void setup() {
  Serial.begin(115200);
  delay(300);

  Wire.begin(Config::SDA_PIN, Config::SCL_PIN);
  pwm.begin();
  pwm.setPWMFreq(Config::SERVO_FREQUENCY_HZ);
  delay(200);
  loadServoCalibration();
  restoreServoState();

  // 安全設計：開機不主動轉動馬達。
  // 僅讀回 PCA9685 已有輸出；收到有效 BLE 指令後才寫入新角度。
  setupBle();

  Serial.println();
  Serial.println("Kova-Hand firmware ready");
  Serial.println("BLE device name: Kova-Hand");
  Serial.println("Waiting for commands...");
}

void loop() {
  updateServos();

  static uint32_t lastStatusMs = 0;
  if (millis() - lastStatusMs >= 2000) {
    lastStatusMs = millis();
    Serial.printf(
        "heartbeat | advertising=%s\n",
        NimBLEDevice::getAdvertising()->isAdvertising() ? "yes" : "no");
  }
  delay(2);
}

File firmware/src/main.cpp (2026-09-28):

// SPDX-FileCopyrightText: 2026 Kova Hand Project
// SPDX-License-Identifier: MIT

// PlatformIO entry point. These includes make the dependency scanner discover
// Arduino core libraries used by the shared Arduino IDE sketch.
#include <Arduino.h>
#include <Preferences.h>
#include <SPI.h>
#include <Wire.h>

#include "../KovaHand/KovaHand.ino"

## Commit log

2026-08-14 chore: stop tracking models and workspace files
    [Part Studio 1 - Bevel 1M 10T 27deg.stl, Part Studio 1 - Bevel 1M 20T 63deg.stl, Part Studio 1 - DIP.stl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]
2026-08-14 chore: ignore CAD model files
